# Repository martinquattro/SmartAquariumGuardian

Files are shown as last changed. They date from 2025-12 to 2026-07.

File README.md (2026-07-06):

# Smart Aquarium Guardian

Smart Aquarium Guardian is an ESP32-based IoT aquarium monitoring and automation system for hobbyists and small-scale aquariums. It combines real-time sensing, automated feeding, remote telemetry, and a local touchscreen interface to help maintain a healthy aquarium with minimal manual effort.

## Overview

This project monitors key aquarium conditions such as water temperature and TDS, supports scheduled feeding, and publishes telemetry to an MQTT broker such as ThingsBoard. It also provides a local user interface built with LVGL so the device can be controlled directly on the hardware.

The system is designed for users who want to:
- monitor aquarium conditions in real time
- receive alerts when values move outside safe thresholds
- automate feeding routines
- configure and control the device remotely

## Key Features

- Real-time monitoring
  - DS18B20 temperature sensing
  - TDS water quality measurement
  - configurable thresholds and alerts

- Automated feeding
  - servo-based food dispenser
  - up to 10 daily feeding schedules
  - manual feeding support

- Connectivity and telemetry
  - Wi-Fi connectivity with automatic reconnection
  - MQTT-based telemetry and remote control
  - access point mode for initial device configuration

- User interface
  - LVGL-based touchscreen UI
  - live sensor values and status indicators
  - feeding and system controls

- System management
  - RTC-based time synchronization
  - timezone-aware scheduling
  - EEPROM-backed configuration storage
  - battery-aware power handling

## System Architecture

The overall system consists of sensors, a control unit, a local display, and cloud connectivity.

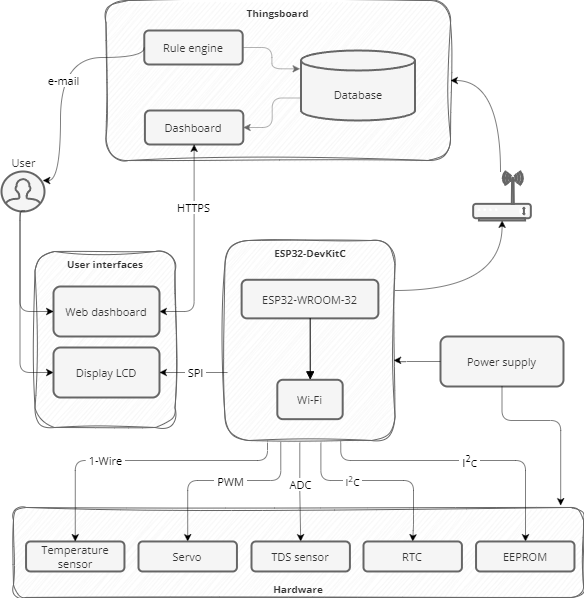
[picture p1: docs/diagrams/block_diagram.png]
System block diagram


### Main building blocks
- Sensors: temperature, TDS, and power monitoring
- Embedded controller: ESP32 firmware and local logic
- Actuators: servo feeder and display backlight/control
- Connectivity: Wi-Fi, MQTT, and remote configuration
- Cloud backend: optional ThingsBoard telemetry and command handling

## Firmware Architecture

The firmware is organized into logical layers for clarity and maintainability.

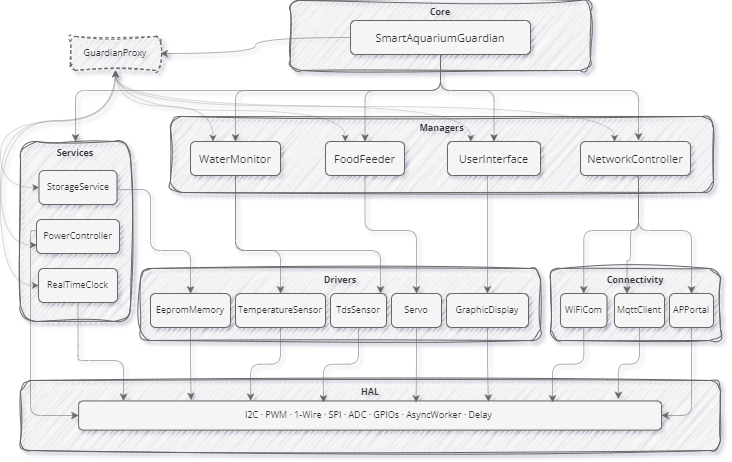
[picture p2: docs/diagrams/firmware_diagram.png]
Firmware architecture diagram


### Layered structure
- Core: shared abstractions, lifecycle patterns, and platform interfaces
- Managers: orchestration of system behavior
- Services: domain-specific logic such as storage and power management
- Drivers: hardware abstraction for sensors and actuators
- Connectivity: Wi-Fi, MQTT, and access-point configuration

For more details, see [src/core/README.md](src/core/README.md).

## Hardware Requirements

The current implementation targets an ESP32-based hardware platform and uses the following components:

- ESP32 development board
- DS18B20 temperature sensor
- TDS sensor with analog input
- servo motor for feeding mechanism
- ILI9341 SPI display with touch support
- optional RTC and EEPROM modules
- USB power with battery backup support

## Software Stack

- PlatformIO
- ESP-IDF
- C++17
- LVGL 9.1.0
- MQTT
- nlohmann-json
- Doxygen for API documentation

## Getting Started

### Prerequisites

- PlatformIO
- ESP-IDF 5.1 or newer
- Python 3.8+
- Doxygen

### Clone the Repository

```bash
git clone https://github.com/your-username/SmartAquariumGuardian.git
cd SmartAquariumGuardian
```

### Build the Project

```bash
pio run -e prod
```

### Flash the Firmware

```bash
pio run -e prod -t upload
```

### Monitor Serial Output

```bash
pio device monitor
```

## Configuration

Main configuration values are defined in [include/config.h](include/config.h) and [platformio.ini](platformio.ini).

Common settings you may want to customize:
- GPIO pin assignments
- MQTT broker address and credentials
- telemetry update interval
- sensor thresholds
- feeding schedules

> Security note: avoid committing sensitive credentials to version control. Prefer local configuration files or environment-based secrets for deployment.

## Usage

After flashing the device:

1. power on the ESP32
2. connect to the device configuration access point if prompted
3. configure Wi-Fi credentials
4. connect to the MQTT broker or cloud backend
5. use the local touchscreen UI or remote commands to interact with the system

The device will begin monitoring sensors, publishing telemetry, and executing scheduled feeds automatically.

## Project Structure

- [src](src): application source code
- [include](include): project-wide configuration headers
- [framework](framework): shared hardware and utility abstractions
- [components](components): third-party and project-local components
- [docs](docs): documentation and supporting assets
- [scripts](scripts): helper scripts such as documentation generation

## Documentation

API documentation is generated with Doxygen.

```bash
doxygen Doxyfile
```

The generated documentation is placed under [docs](docs).

## License

This project is licensed under the MIT License. See [LICENSE](LICENSE) for details.

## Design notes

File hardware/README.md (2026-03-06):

# Hardware Design - Smart Aquarium Guardian

This directory serves as the central repository for all electronic design files (EDA) related to the **Smart Aquarium Guardian** project. The hardware architecture is modular, consisting of the Main Controller Board and the Power Supply Board.

## 📂 Modules

### 1. Main Controller Board (Current Active Project)
This is the core of the system, responsible for:
* **Processing:** ESP32 Microcontroller logic.
* **Sensing:** Interfaces for TDS (Total Dissolved Solids) and Temperature sensors.
* **Actuation:** Control signals for external peripherals.

### 2. Power Supply Board
Provides mains-independent operation with USB charging and battery backup. Key features:
* **USB Type-C Input:** Power-only 6P receptacle for 5V charging.
* **Li-ion/LiPo Charging:** TP4056 1A linear charger for single-cell batteries (4.2V).
* **Battery Backup:** Automatic switch to battery when USB power is lost (power path switching via P-Channel MOSFET).
* **Boost Output:** MT3608 step-up DC-DC converter to supply stable 5V from battery to the main controller.
* **Status Indicators:** Red (charging) and green (charged) LEDs.
* **Output:** Connector for main board power supply.

## 🛠️ Directory Structure & Portability

The project is designed using **KiCad EDA**. It is structured to be **fully self-contained**, meaning no external global libraries are required to view or edit the files.

```text
/kicad
├── .gitignore                   # gitignore file for this folder
├── smart_aquarium_guardian/     # Main Controller Board
│   ├── lib/                     # Project-specific Local Libraries
│   │   ├── *.kicad_sym          # Custom Schematic Symbols
│   │   └── Guardian.pretty/     # Custom PCB Footprints
│   ├── datasheets/              # Technical documentation for critical components
│   ├── fp-lib-table             # Footprint Library Table (Maps local footprints)
│   ├── sym-lib-table            # Symbol Library Table (Maps local symbols)
│   ├── smart_aquarium_guardian.kicad_pro
│   ├── smart_aquarium_guardian.kicad_sch
│   └── smart_aquarium_guardian.kicad_pcb
│
└── power_supply/                # Power Supply Board
    ├── lib/                     # Power Supply Local Libraries
    │   ├── Power_Supply.kicad_sym
    │   └── PowerSupply.pretty/
    ├── production/              # Manufacturing outputs (Gerbers, BOM, drill files)
    ├── fp-lib-table
    ├── sym-lib-table
    ├── power_supply.kicad_pro
    ├── power_supply.kicad_sch
    └── power_supply.kicad_pcb
```

## 🚀 Usage & Workflow

To ensure the integrity of the design and library links, please follow these steps:

### Prerequisites
* **Software:** KiCad EDA
* **Version:** **9.0** or later.
  * *Note: Files saved in KiCad 9.0 are not backward compatible with older versions (6.0/7.0/8.0).*

### How to Open
1. **Clone the Repository:**
   Ensure you have the full directory structure, as the project relies on relative paths.
2. **Launch KiCad:**
   Open the desired project file (`.kicad_pro`):
   * Main Controller: `kicad/smart_aquarium_guardian/smart_aquarium_guardian.kicad_pro`
   * Power Supply: `kicad/power_supply/power_supply.kicad_pro`
3. **Access Design Files:**
   * **Schematic:** Open the Schematic Editor (`.kicad_sch`) to view the logical connections.
   * **PCB Layout:** Open the PCB Editor (`.kicad_pcb`) to view the physical routing and placement.

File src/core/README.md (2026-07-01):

# Core Architecture

## Overview

The core module contains the foundational architecture of Smart Aquarium Guardian. It defines the reusable abstractions and patterns used throughout the firmware, including lifecycle management, communication contracts, and module coordination.

## Firmware Architecture Layers

The firmware is organized into a layered architecture to keep the system modular and maintainable.

Firmware architecture diagram

### 1. Core layer
Provides shared infrastructure for the entire system:
- base module lifecycle
- singleton patterns
- common interfaces and abstractions

### 2. Managers
Coordinate high-level behavior and orchestrate other subsystems:
- network management
- feeding control
- water monitoring
- UI coordination

### 3. Services
Implement domain-specific functionality:
- storage
- power handling
- real-time clock integration
- configuration and persistence logic

### 4. Drivers
Wrap hardware access in reusable abstractions:
- temperature sensors
- TDS sensing
- display control
- servo control
- I2C and GPIO utilities

### 5. Connectivity
Handles communication with the outside world:
- Wi-Fi setup and reconnection
- MQTT communication
- access-point configuration flow

### 6. UI
Responsible for local interaction:
- touchscreen input handling
- LVGL rendering
- status and control screens

## Design Principles

The architecture favors:
- separation of concerns
- clear module boundaries
- dependency inversion where appropriate
- centralized coordination through proxy or facade patterns

## Key Components

- GuardianProxy: central entry point for system operations
- GuardianPublicInterfaces: public contract exposed to upper layers
- Base module abstractions: reusable building blocks for managers, drivers, and services

## Relationship to the Rest of the Project

The core layer provides the foundation for managers, services, and drivers. The rest of the firmware depends on these abstractions rather than directly coupling to concrete implementations.

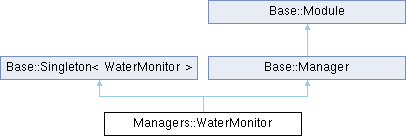
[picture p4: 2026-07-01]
docs/doxygen/html/class_managers_1_1_water_monitor.png

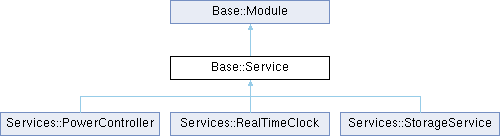
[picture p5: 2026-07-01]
docs/doxygen/html/class_base_1_1_service.png

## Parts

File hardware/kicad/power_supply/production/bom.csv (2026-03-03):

Designator | Footprint | Quantity | Value | LCSC Part #
C1, C3 | 0402 | 2 | 10uF | C15525
C2, C4 | 1206 | 2 | 22uF | C12891
D1, D4 | D_SMA | 2 | SS34 | C8678
D2 | 0805 | 1 | RED | C84256
D3 | 0805 | 1 | GREEN | C2297
J1 | TYPE-C-SMD_TYPE-C-6P | 1 | USB_C_Receptacle_PowerOnly_6P | C456012
L1 | IND-SMD_2P-L5.0-W5.0 | 1 | 10uH | C9389
Q1 | SOT-23 | 1 | AO3401A | C15127
R1, R2 | 0805 | 2 | 5.1k | C27834
R3 | 0805 | 1 | 2.4k | C17526
R4 | 0805 | 1 | 100k | C149504
R5, R6 | 0805 | 2 | 1k | C17513
R7 | 0805 | 1 | 110k | C17422
R8 | 0805 | 1 | 15k | C17475
U1 | SOIC-8-1EP_3.9x4.9mm_P1.27mm_EP2.41x3.3mm_ThermalVias | 1 | TP4056-42-ESOP8 | C16581
U2 | TSOT-23-6_HandSoldering | 1 | MT3608 | C84817

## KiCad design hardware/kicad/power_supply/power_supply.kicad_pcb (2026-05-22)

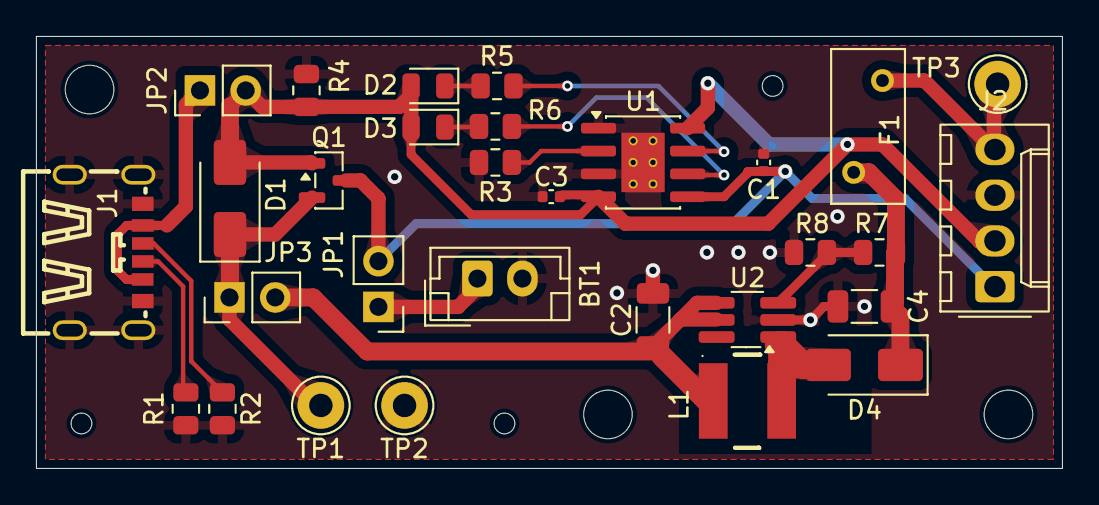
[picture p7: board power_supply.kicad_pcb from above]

Board: 2 copper layers, 57.0 x 24.0 mm, 36 parts (0 on the bottom side), 18 nets.

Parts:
BT1: Battery_Cell; JST_EH_B2B-EH-A_1x02_P2.50mm_Vertical
C1, C3: 10uF; C_0402_1005Metric
C2, C4: 22uF; C_1206_3216Metric
D1, D4: SS34; D_SMA
D2: RED; LED_0805_2012Metric
D3: GREEN; LED_0805_2012Metric
F1: Fuse; Fuse_BelFuse_0ZRE0005FF_L8.3mm_W3.8mm
J1: USB_C_Receptacle_PowerOnly_6P; TYPE-C-SMD_TYPE-C-6P
J2: PINHD_1x4_Female; Molex_KK-254_AE-6410-04A_1x04_P2.54mm_Vertical
JP1: Bat; PinHeader_1x02_P2.54mm_Vertical
JP2: usb; PinHeader_1x02_P2.54mm_Vertical
JP3: power; PinHeader_1x02_P2.54mm_Vertical
L1: 10uH; IND-SMD_2P-L5.0-W5.0
M1, M2, M6: MountingHole_2.7mm
M3, M4, M5: MountingHole_2.2mm_M2
Q1: AO3401A; SOT-23
R1, R2: 5.1k; R_0805_2012Metric
R3: 2.4k; R_0805_2012Metric
R4: 100k; R_0805_2012Metric
R5, R6: 1k; R_0805_2012Metric
R7: 110k; R_0805_2012Metric
R8: 15k; R_0805_2012Metric
TP1: TestPoint; Pin_D1.3mm_L11.0mm
TP2: gnd; Pin_D1.3mm_L11.0mm
TP3: out; Pin_D1.3mm_L11.0mm
U1: TP4056-42-ESOP8; SOIC-8-1EP_3.9x4.9mm_P1.27mm_EP2.41x3.3mm_ThermalVias
U2: MT3608; TSOT-23-6_HandSoldering

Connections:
/Boost_{OUT}: C4.1, D4.1 (K), F1.1, R7.1
GND: BT1.2 (-), C1.2, C2.2, C3.2, C4.2, J1.7 (SHIELD), J1.A12 (GND), J1.B12 (GND), J2.3 (GND), R1.2, R2.2, R3.2, R4.2, R8.2, TP2.1, U1.1 (TEMP), U1.3 (GND), U1.9 (EPAD), U2.2 (GND)
unnamed: BT1.1 (+), JP1.1 (A)
unnamed: D1.1 (K), JP3.1 (A), Q1.2 (S), TP1.1
unnamed: D2.1 (K), R5.1
unnamed: D3.1 (K), R6.1
unnamed: D4.2 (A), L1.2, U2.1 (SW)
unnamed: J1.A5 (CC1), R2.1
unnamed: J1.B5 (CC2), R1.1
unnamed: F1.2, J2.4 (Vout), TP3.1
unnamed: J1.A9 (VBUS), J1.B9 (VBUS), JP2.1 (A)
unnamed: C2.1, JP3.2 (B), L1.1, U2.4 (EN), U2.5 (IN)
unnamed: R3.1, U1.2 (PROG)
unnamed: R5.2, U1.7 (~CHRG)
unnamed: R6.2, U1.6 (~STDBY)
unnamed: R7.2, R8.1, U2.3 (FB)
V_{bat}: C1.1, J2.1 (VBat), JP1.2 (B), Q1.3 (D), U1.5 (BAT)
V_{in}: C3.1, D1.2 (A), D2.2 (A), D3.2 (A), J2.2 (Vusb), JP2.2 (B), Q1.1 (G), R4.1, U1.4 (V_{CC}), U1.8 (CE)

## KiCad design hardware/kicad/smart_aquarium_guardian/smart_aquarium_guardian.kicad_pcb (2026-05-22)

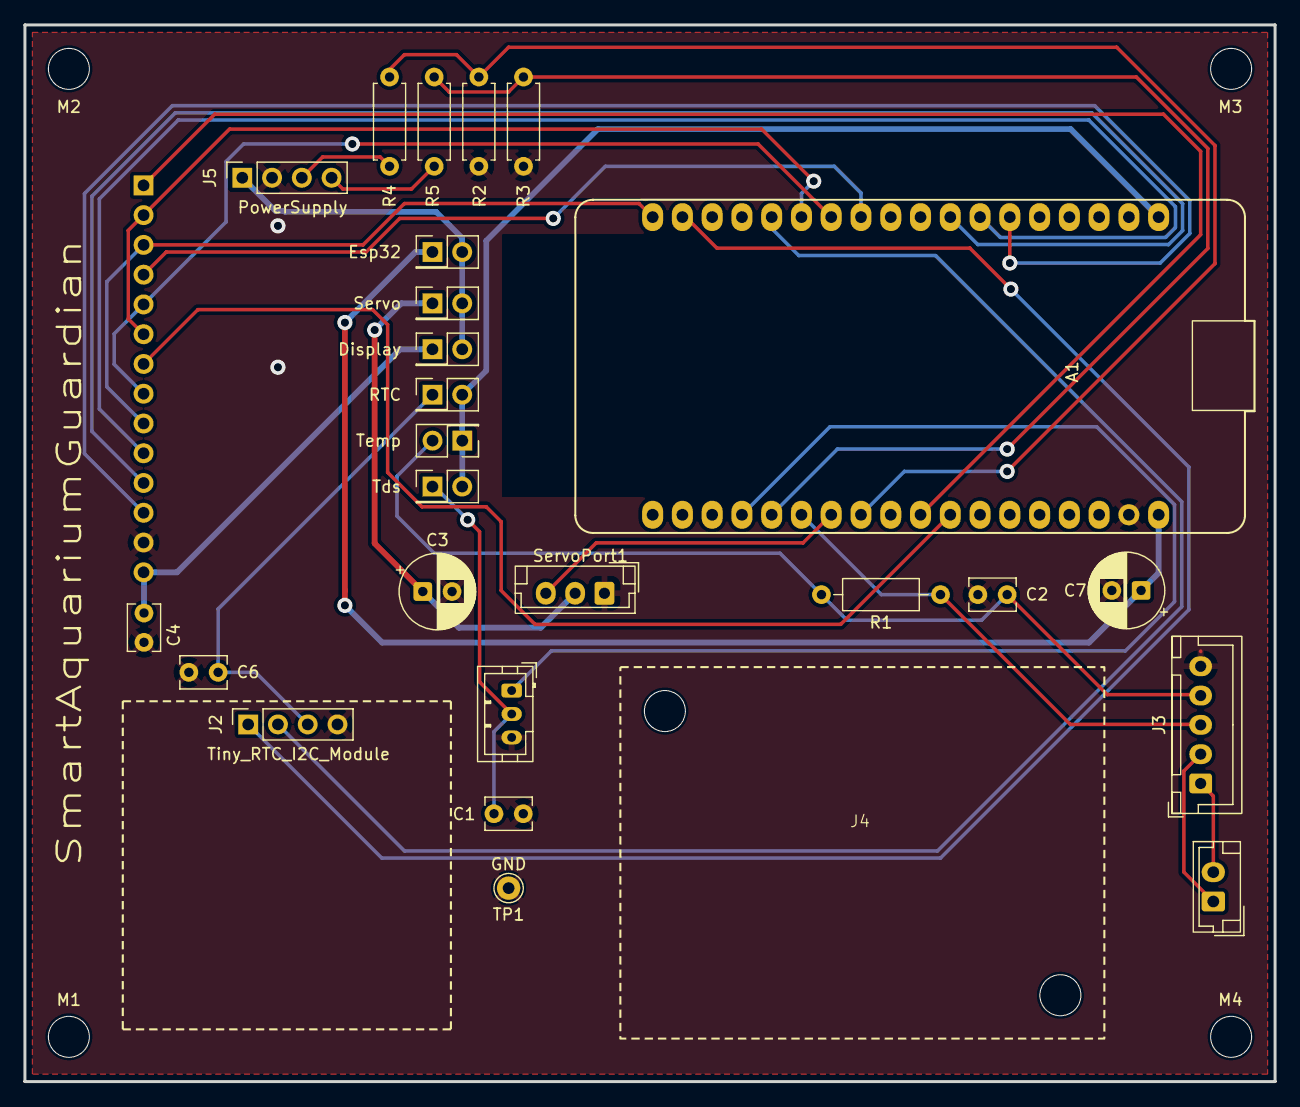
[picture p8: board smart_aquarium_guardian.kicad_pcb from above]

Board: 2 copper layers, 106.7 x 90.2 mm, 29 parts (1 on the bottom side), 29 nets.

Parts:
A1: ESP32_DevKit1.1; DOIT_ESP32_DEVKIT_36Pins
C1, C2, C4, C6: 100n; C_Disc_D3.8mm_W2.6mm_P2.50mm
C3: 470u; CP_Radial_D6.3mm_P2.50mm
C7: 1000u; CP_Radial_D6.3mm_P2.50mm
J1: Display_2.8_TFT_240xRGBx320; PinSocket_1x14_P2.54mm_Vertical
J2: Tiny_RTC_I2C_Module; PinSocket_1x04_P2.54mm_Vertical
J3: SensorsInput; JST_XH_B5B-XH-A_1x05_P2.50mm_Vertical
J4: TdsMeter; tds_meter_module
J5: PowerSupply; PinSocket_1x04_P2.54mm_Vertical
JP1: Display; PinHeader_2x01_P2.54mm_Vertical
JP2: RTC; PinHeader_2x01_P2.54mm_Vertical
JP3: Servo; PinHeader_2x01_P2.54mm_Vertical
JP4: Temp; PinHeader_2x01_P2.54mm_Vertical
JP5: Esp32; PinHeader_2x01_P2.54mm_Vertical
JP6: Tds; PinHeader_2x01_P2.54mm_Vertical
M1, M2, M3, M4: MountingHole_3.5mm
R1: 4K7; R_Axial_DIN0207_L6.3mm_D2.5mm_P10.16mm_Horizontal
R2: 22K; R_Axial_DIN0207_L6.3mm_D2.5mm_P7.62mm_Horizontal
R3, R5: 100K; R_Axial_DIN0207_L6.3mm_D2.5mm_P7.62mm_Horizontal
R4: 10K; R_Axial_DIN0207_L6.3mm_D2.5mm_P7.62mm_Horizontal
ServoPort1: MG90s_Micro_servo; JST_EH_B3B-EH-A_1x03_P2.50mm_Vertical
TP1: GND; Pin_D1.0mm_L10.0mm

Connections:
3V3: A1.1 (3.3V), JP2.2 (B), JP4.1 (A), JP6.2 (B)
5V: J5.1 (VCC), JP1.2 (B), JP3.2 (B), JP5.2 (B)
/LED_BKL: A1.29 (ADC2_CH6/D14), J1.7 (LED)
/LED_CS: A1.6 (D15), J1.12 (CS)
/LED_CS_{touch}: A1.11 (D5), J1.4 (T_CS)
/LED_DO: A1.7 (D2), J1.10 (DO)
/LED_IRQ_{touch}: A1.28 (ADC2_CH7/D27), J1.1 (T_IRQ)
/LED_RST: A1.8 (D4), J1.11 (RESET)
/LED_SCK: A1.12 (D18), J1.5 (T_CLK), J1.8 (SCK)
/LED_SDI: A1.18 (D23), J1.3 (T_DIN), J1.9 (SDI)
/LED_SDO: A1.13 (D19), J1.2 (T_DO), J1.6 (SDO)
/RTC_SCL: A1.17 (D22/SCL), J2.1 (SCL)
/RTC_SDA: A1.14 (D21/SDA), J2.2 (SDA)
/SERVO_PWM: A1.25 (ADC1_CH5/D33), ServoPort1.1 (IN1)
/TDS_DATA: A1.22 (ADC1_CH6/D34), J4.1
/TEMP_DATA: A1.24 (ADC1_CH4/D32), J3.3, R1.1
/V_BAT*: A1.23 (ADC1_CH7/D35), R3.2, R5.1
/V_USB*: A1.26 (DAC1/ADC2_CH8/D25), R2.2, R4.1
GND: A1.35 (GND), C1.2, C2.2, C3.2, C4.2, C6.2, C7.2, J1.13 (GND), J2.4 (GND), J3.5, J4.3, J5.2 (GND), R2.1, R3.1, ServoPort1.3, TP1.1
unnamed: A1.36 (VIN), C7.1, JP5.1 (A)
unnamed: C4.1, J1.14 (VCC), JP1.1 (A)
unnamed: C6.1, J2.3 (VCC), JP2.1 (A)
unnamed: J3.1, J4.5
unnamed: J3.2, J4.4 (Pin_5)
unnamed: C1.1, J4.2, JP6.1 (A)
unnamed: J5.4 (VBAT), R5.2
unnamed: J5.3 (VUSB), R4.2
unnamed: C3.1, JP3.1 (A), ServoPort1.2
unnamed: C2.1, J3.4, JP4.2 (B), R1.2

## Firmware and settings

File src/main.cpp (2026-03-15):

/*!****************************************************************************
 * @file    main.cpp
 * @brief   Implementation of the main application entry point for the Smart Aquarium Guardian. 
 * @author  Quattrone Martin
 * @date    Aug 2025
 *******************************************************************************/

#include "src/core/smart_aquarium_guardian.h"

//-----------------------------------------------------------------------------
extern "C" void app_main(void) 
{
    SmartAquariumGuardian::GetInstance()->Init(2000);

    while (true) 
    {
        SmartAquariumGuardian::GetInstance()->Update(10);
    }
}

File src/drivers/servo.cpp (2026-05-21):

/*!****************************************************************************
 * @file    servo.cpp
 * @brief   Implementation of Servo class for PWM control of servo motors.
 * @author  Quattrone Martin
 * @date    Aug 2025
 ******************************************************************************/

#include "src/drivers/servo.h"

#include "include/config.h"
#include <algorithm>

namespace Drivers {

//----private------------------------------------------------------------------
bool Servo::OnInit()
{
    SetAngle(180.0f);
    return true;
}

//----private------------------------------------------------------------------
void Servo::OnUpdate()
{
    // For now, no periodic logic.
    // In the future, could track Fade completion or add timed sequences.
}

//-----------------------------------------------------------------------------
void Servo::SetAngle(float angle)
{
    angle = std::clamp(angle, 0.0f, 180.0f);

    float duty = MIN_SAFE_DUTY + (angle / 180.0f) * (MAX_SAFE_DUTY - MIN_SAFE_DUTY);

    _pwmOut.SetDuty(duty);
}

//-----------------------------------------------------------------------------
void Servo::FadeToAngle(float angle, uint32_t timeMs)
{
    angle = std::clamp(angle, 0.0f, 180.0f);

    float duty = MIN_SAFE_DUTY + (angle / 180.0f) * (MAX_SAFE_DUTY - MIN_SAFE_DUTY);

    _pwmOut.FadeToDuty(duty, timeMs);
}

//-----------------------------------------------------------------------------
void Servo::Release()
{
    _pwmOut.Stop();
}

//----private------------------------------------------------------------------
Servo::Servo()
    : _pwmOut(Config::SERVO_FEEDER_PWM_PIN, PWM_FREQUENCY)
{}

} // namespace Drivers

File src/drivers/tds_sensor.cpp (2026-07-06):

/*!****************************************************************************
 * @file    tds_sensor.cpp
 * @brief   Implementation of the TdsSensor class functions.
 * @author  Quattrone Martin
 * @date    Aug 2025
 ******************************************************************************/

#include "src/drivers/tds_sensor.h"

#include "include/config.h"
#include <algorithm>
#include <cmath>

namespace Drivers {

//----private------------------------------------------------------------------
bool TdsSensor::OnInit()
{
    _temperature = 25.0f; // Default to 25°C for initial readings
    _lastReading = 0;
    return true;
}

//-----------------------------------------------------------------------------
void TdsSensor::OnUpdate()
{
    const float analogReading = _analogInPin.ReadVoltage(64);
    const float avgAnalogReading = StoreAnalogReading(analogReading);

    // Logic to transform reading to ppm units
    // ppm = (133.42 * V³ - 255.86 * V² + 857.39 * V) / factorTemp * 0.5
    // factorTemp ≈ 1.0 + 0.02 * (temp - 25)
    float factorTemp = (1.0 + 0.02 * (_temperature - 25.0));

    _lastReading = (133.42 * pow(avgAnalogReading, 3) 
                     - 255.86 * pow(avgAnalogReading, 2) 
                     + 857.39 * avgAnalogReading) / factorTemp * 0.5;

    _lastReading = std::clamp(_lastReading, MIN_TDS_VALUE, MAX_TDS_VALUE);

    CORE_INFO("Tds avg reading - PPM = %d", _lastReading);
}

//-----------------------------------------------------------------------------
int TdsSensor::GetLastReading()
{
    // return rand() % 1000;
    return _lastReading;
}

//----private------------------------------------------------------------------
float TdsSensor::StoreAnalogReading(const float reading)
{
    if (reading < 0.0f || reading > 3.3f)
    {
        CORE_ERROR("Invalid analog reading: %.4f", reading);
        return 0.0f;
    }

    // Add reading to vector
    (*_analogReadingsVecIter) = reading;

    // Check if we were at last element of the readings vector
    if (_analogReadingsVecIter++ >= _analogReadingsVec.end())
    {
        _analogReadingsVecIter = _analogReadingsVec.begin();
    }

    // Obtain average
    float tdsReadingSum = 0.0;
    int amountOfReadings = 0;
    for (auto it = _analogReadingsVec.begin(); it != _analogReadingsVec.end(); ++it) 
    {
        if ((*it) > -1.0f)
        {
            tdsReadingSum += (*it);
            ++amountOfReadings;
        }
    }

    float avgAnalogReading = (tdsReadingSum / amountOfReadings);
    return avgAnalogReading;
}

//----private------------------------------------------------------------------
TdsSensor::TdsSensor()
    : _analogInPin(Config::TDS_SENSOR_ADC_PIN)
    , _analogReadingsVec(NUM_AVG_SAMPLES, -1.0)
    , _analogReadingsVecIter(_analogReadingsVec.begin())
{
}

} // namespace Drivers

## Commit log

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2025-08-14 Refactor DigitalOut to DigitalInOut for GPIO control
    Replaces DigitalOut with a new DigitalInOut class supporting input, output, and input/output modes. Updates relevant includes and implementation files, and adds a BUILTIN_LED pin definition in config.h.
    [digital_in_out.cpp]
2025-08-15 Add Delay utility and integrate in SmartAquariumGuardian
    Introduced a Delay class for periodic timing in ESP32 projects. Integrated Delay into SmartAquariumGuardian to control update intervals, improving timing and reducing flickering with a debounce delay.
2025-08-15 Refactor include paths for consistency and clarity
    Updated include paths across framework and src files to use explicit relative paths, improving consistency and reducing ambiguity. Adjusted CMakeLists.txt and platformio.ini to match new structure and ensure correct build configuration. No functional changes, only path and build system improvements.
    [analog_in.cpp, digital_in_out.cpp, main.cpp]
2025-08-16 Refactor AnalogIn for calibrated voltage reading
    Reworked AnalogIn to use ESP-IDF ADC calibration for accurate voltage readings. Deprecated raw and normalized read methods, added ReadCalibrated for millivolt output, and updated pin-to-channel conversion logic. Enhanced debug macros and renamed delay macro for clarity.
    [analog_in.cpp]
2025-08-16 Refactor TdsSensor analog reading and calculation
    Renamed internal variables for clarity, implemented TDS calculation using temperature compensation, and updated logging. Improved averaging logic and replaced legacy code with a more accurate ppm conversion.
    [tds_sensor.cpp]
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2025-08-26 Add LcdDisplay and UserInterface classes
    Working with some text samples in the Update
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2025-09-09 Add DateTime utility and integrate with RTC
    Introduced a new Utilities::DateTime class for time manipulation and formatting. Refactored RealTimeClock to use DateTime objects for getting and setting time, and updated UserInterface to display th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
2025-10-25 Add MQTT client integration and update WiFiCom API
    Introduced a new MQTT client wrapper (esp-mqtt) with publish/subscribe API in src/connectivity/mqtt_client.{h,cpp}. Updated CMake and PlatformIO configuration to include MQTT and custom partition tab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
    [partitions.csv]
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2025-10-26 Enhance water monitor and UI with live sensor data
    Added methods to WaterMonitor for retrieving live temperature and TDS readings, and exposed WiFi/MQTT connection status in NetworkController. Updated UserInterface to display real-time sensor values 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
2025-11-22 Add RPC handler framework and temperature limits support
    Introduces a generic RPC handler interface and a specific handler for setting temperature limits. Refactors NetworkController to dispatch MQTT messages and handle RPC requests using the new handler s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
2025-11-22 Refactor RPC and temperature limit handling with Result type
    Introduces a unified Result struct for operation outcomes in common_defs.h and replaces previous custom RpcResult usage. Refactors SetTemperatureLimits methods and related interfaces to return Result instead of bool, improving error handling and messaging. Adds a new utility class JsonPayloadParser for robust, exception-safe JSON parsing and parameter extraction, and updates RPC handler and network controller logic to use this parser for payload validation and method dispatch.
2025-11-22 Add feeding schedule RPC handlers
    Introduced AddFeedingScheduleHandler, DeleteFeedingScheduleHandler, and FeedNowHandler classes to handle new RPC commands for feeding schedules. Registered these handlers in NetworkController and upd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
2025-12-03 Add enabled flags for temperature limits in RPC handler
    Introduces TEMP_LIMIT_MIN_ENABLED and TEMP_LIMIT_MAX_ENABLED attributes to network_config.h and updates SetTempLimitsHandler to validate and handle these flags. The handler now checks if limit values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
2025-12-05 Refactor config storage and add temp limit support
    Replaces IDataStore with IStorageService and updates GuardianProxy and related interfaces to support saving and retrieving temperature limits with enable flags. Refactors configuration storage to use a new MemoryConfigData struct with field-based access, and updates StorageService to provide generic Get/Set methods for config fields. Moves EEPROM memory files to a new directory and removes the old memory_config_data.h. Updates WaterMonitor and RPC handler to use the new temperature limit interface and validation.
    [eeprom_memory.cpp]
2025-12-06 Add thread safety to I2C and validate temperature limits
    Introduced a mutex to the I2C driver for thread-safe operations. Updated WaterMonitor to validate temperature limits against defined min/max values before saving. Minor code cleanups and improved error handling. Also adjusted monitor filters in platformio.ini and fixed formatting in network_config.h.
    [i2c.cpp]
2025-12-06 Add async food feeding with dose control
    Introduces AsyncWorker for running background tasks and integrates it into FoodFeeder to allow asynchronous feeding of a specified dose. Updates IFoodFeeder and GuardianProxy interfaces to support do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
2025-12-06 Add feeding status LED indicator support
    Introduced a simple LED driver and integrated a feeding status indicator LED into the user interface. Updated the food feeder logic to toggle the indicator during feeding sequences. Added relevant in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
2025-12-08 Refactor OneWire pin control and timing
    Calls Release() in the constructor for initial pin state. Adjusts timing in Reset() for presence detection. Simplifies DriveLow() and Release() methods to set pin level instead of changing direction and pull mode.
    [one_wire.cpp]
2025-12-11 Add ESP LCD ILI9341 and touch panel components
    Introduced new components for the ILI9341 LCD controller and various LCD touch controllers (CST816S, FT5X06, GT1151, GT911, STMPE610, TT21100) with their respective source, headers, CMake, and test f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
    [partitions.csv]
2025-12-11 Migrate from LCD to graphic display with LVGL
    Replaces the old 20x4 LCD display driver with a new ILI9341 graphic display driver using LVGL and XPT2046 touch support. Updates pin assignments and configuration for the new display, removes LCD-specific code, and adapts the user interface manager to use the new graphic display. Also updates dependencies and build configuration to support the new display stack.
    [graphic_display.cpp]
2025-12-12 Add UIElement abstraction for LVGL text elements
    Introduced the UIElement class in GraphicDisplay to encapsulate LVGL label creation, text, and status color management. Added font size and status enums, and a CreateTextElement method for flexible U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
2025-12-13 Add line and ring UI elements to GraphicDisplay
    Introduces CreateLine and CreateRing methods to GraphicDisplay for drawing lines and rings on the display. Adds ElementColor enum and related color/style methods to UIElement. Refactors UserInterface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
2026-01-05 Integrate new UI system and refactor display logic
    Replaces custom UI element creation and management in GraphicDisplay and UserInterface with a new UI system generated by SquareLine Studio. Adds the src/ui directory with generated C files, images, and fonts, and updates CMakeLists to include these sources. Refactors UserInterface to use new UI element handles and removes legacy display state logic and element creation methods.
    [graphic_display.cpp]
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2026-01-11 Add display brightness control and update sensor logic
    Introduced backlight brightness control to GraphicDisplay using PWM, including new SetBrightness method and constructor parameter. Fixed temperature and TDS sensor averaging logic to use correct thresholds, enabled WaterMonitor update in SmartAquariumGuardian, and improved temperature display formatting in UserInterface. Added lv_conf.h for LVGL configuration.
    [graphic_display.cpp, pwm_out.cpp, tds_sensor.cpp]
2026-01-11 Improve OneWire concurrency and add CRC to temperature sensor
    Added critical section protection to OneWire operations for thread safety. Implemented CRC8 validation for DS18B20 temperature sensor readings and improved error handling for invalid readings. Disabled FoodFeeder manager update in SmartAquariumGuardian. Restored TdsSensor to return actual readings instead of random values.
    [one_wire.cpp, tds_sensor.cpp]
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2026-01-28 Refactor DateTime retrieval to use output parameter
    Changed the GetDateTime and GetTime methods to use an output parameter and return a success flag instead of returning a DateTime object. Updated all usages and interfaces accordingly for improved error handling and consistency.
    [food_feeder.cpp, i2c.cpp]
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2026-02-07 Add KiCad hardware project for aquarium guardian
    Add a self-contained KiCad hardware project for the Smart Aquarium Guardian. Changes include: updated root .gitignore (add *.ini and docs/), new hardware/.gitignore and hardware/README.md with KiCad 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
    [smart_aquarium_guardian.kicad_pcb]
2026-02-13 Changes made after recommendations before printing it
    [smart_aquarium_guardian.kicad_pcb]
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2026-02-22 Add KiCad power_supply project and libs
    Add a complete KiCad power_supply project under hardware/kicad/power_supply. Includes project files (.kicad_pro, .kicad_sch, .kicad_pcb), library tables (fp-lib-table, sym-lib-table), footprints and 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
    [power_supply.kicad_pcb, power_supply.kicad_sch]
2026-02-28 First draft completed for the power supply kicad project
    [power_supply.kicad_pcb, power_supply.kicad_sch, smart_aquarium_guardian.kicad_pcb]
2026-03-03 Final version for power supply circuit
    [bom.csv, designators.csv, positions.csv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]
2026-03-03 Update datasheets
    [power_supply.kicad_sch]
2026-03-03 Remove unnecesary footprint and symbol libraries
    [power_supply.kicad_pcb]
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2026-03-08 Add a recovery time after each power mode to avoid flickering
2026-03-14 Refactor MQTT configuration: remove MQTT handling from APPortal, add MQTT client configuration constants, and update HTML content for WiFi setup.
    [framework.cfg]
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2026-03-15 Update SmartAquariumGuardian and UserInterface initialization to include delay parameters, enhance UI screen loading with splash screen.
    [framework.cfg]
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2026-05-22 Visual changes on KiCAD projects
    [power_supply.kicad_pcb, power_supply.kicad_sch, smart_aquarium_guardian.kicad_pcb]
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
